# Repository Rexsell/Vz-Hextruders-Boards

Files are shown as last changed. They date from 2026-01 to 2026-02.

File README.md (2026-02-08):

This project introduces convenient and useful PCBs designed for the [Vz-Hextrudort-Low](https://github.com/VzBoT3D/Vz-HextrudORT) and [Vz-Hextrudort-Plus](https://aliexpress.com/item/1005006121253410.html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)
Currently, there are no fully suitable toolboards for VzHextruders, as existing options require additional printed parts and are not 100% compatible with the [Vz-Printhead](https://github.com/VzBoT3D/Vz-Printhead-CNC)

# Prerequisites

Before installation, ensure you have a compatible [X-Endstop mount](https://www.printables.com/model/1297201-x-endstop-mount)
Also, use the correct hardware:
- M3x25 screw (for both extruders)
- M3x6 screw (Hextrudort-Low)
- M3x16 screw (Hextrudort-Plus)
- M3 standoffs (Length equal to your motor's height. You may also need a 0.5mm spacer for LDO motors.)
  
# Boards

## [VzHextrudortLow](https://github.com/Rexsell/Vz-Hextrudort-Boards/tree/main/VzHextrudortLow "VzHextrudortLow") and [VzHextrudortPlus](https://github.com/Rexsell/Vz-Hextrudort-Boards/tree/main/VzHextrudortPlus "VzHextrudortPlus")

They are simple commutation boards, they require Molex Microfit 2x10 as an input. Just direct connection, simple yet useful.

<p align="left">
  Vz-Hextrudort-Low
  Vz-Hextrudort-Plus
</p>

## [VzHextrudortPlusCan](https://github.com/Rexsell/Vz-Hextrudort-Boards/tree/main/VzHextrudortPlusCan "VzHextrudortPlusCan") and [VzHextrudortPlusUSB](https://github.com/Rexsell/Vz-Hextrudort-Boards/tree/main/VzHextrudortPlusUSB "VzHextrudortPlusUSB")
These are already CAN and USB boards respectively. USB version has several additional USB connectors for Beacon/Cartographer sensors and other devices. CAN board has only one CAN connector for external devices.

First of all, they are simpled version of toolboards. They were made as two-layer, singlesided PCBs in order to reduce cost and make them assemblable at home.
Secondly, CAN version I ordered and assembled two times, second one I corrected several mistakes. 

Features:
- Onboard NTC sensor
- TMC2209
- Connectors for external probes
- Connector for FilGuard sensor (Supports simple endstop)
- MAX31865 (Only for USB version curently)
- Solder jumper to turn off power LEDs
- RGB LED for motor backlight (Only for USB)
- Molex Microfit 3.0 for heater
- PFET protection from reversed polarity
- 2 Fans connectors
  
<p align="left">
  Hextruder Photo
  Hextruder Photo 2
</p>

## WARNING!!!

**Before using this project, double-check the hotnd sensor connector schematic. I experienced unstable readings due to this configuration. The cause could be poorly chosen components, suboptimal routing, or a faulty schematic. The issue was completely resolved after connecting the same PT1000 sensor to a MAX31865 board. I used the BTT EBB36 schematic as a reference, but I don't recall exactly how I selected the components — I may have chosen incorrect ones.**

## [VzLowCan-Pro](https://github.com/Rexsell/Vz-Hextrudort-Boards/tree/main/VzLowCan-Pro "VzLowCan-Pro")

It shares the same features (and issues) as the [VzHextrudortPlusUSB](https://github.com/Rexsell/Vz-Hextrudort-Boards/tree/main/VzHextrudortPlusUSB "VzHextrudortPlusUSB"). However, this version is adapted for the -Low model and includes several additional features, such as an extended configuration for the MAX31865 and a connector for a probe like the BL-Touch. It also has a jumper for fan voltage selection. The design is not yet finalized, but I believe more experienced engineers will be able to complete it.

<p align="left">
  VzLowCan-Pro
  VzLowCan-Pro SolidWorks
</p>

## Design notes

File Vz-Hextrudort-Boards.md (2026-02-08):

This project introduces convenient and useful PCBs designed for the [Vz-Hextrudort-Low](https://github.com/VzBoT3D/Vz-HextrudORT) and [Vz-Hextrudort-Plus](https://aliexpress.com/item/1005006121253410.html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)
Currently, there are no fully suitable toolboards for VzHextruders, as existing options require additional printed parts and are not 100% compatible with the [Vz-Printhead](https://github.com/VzBoT3D/Vz-Printhead-CNC)

# Prerequisites

Before installment, make sure you have suitable [X-Endstop mount](https://www.printables.com/model/1297201-x-endstop-mount)
Also, use proper hardware:
- M3x25 screw (for both extruders)
- M3x6 screw (Hextrudort-Low)
- M3x16 screw (Hextrudort-Plus)
- M3 standoffs (Equals for your motor length. You may also need 0.5 spacer for LDO motors)
# Boards

## [VzHextrudortLow](https://github.com/Rexsell/Vz-Hextrudort-Boards/tree/main/VzHextrudortLow "VzHextrudortLow") and [VzHextrudortPlus](https://github.com/Rexsell/Vz-Hextrudort-Boards/tree/main/VzHextrudortPlus "VzHextrudortPlus")

They are simple commutation boards, they require Molex Microfit 2x10 as an input. Just direct connection, simple yet useful.
![[Hextrudort-Low commutation board.png]]
![[Hextrudort-Plus commutation board.png]]
## [VzHextrudortPlusCan](https://github.com/Rexsell/Vz-Hextrudort-Boards/tree/main/VzHextrudortPlusCan "VzHextrudortPlusCan") and [VzHextrudortPlusUSB](https://github.com/Rexsell/Vz-Hextrudort-Boards/tree/main/VzHextrudortPlusUSB "VzHextrudortPlusUSB")
These are already CAN and USB boards respectively. USB version has several additional USB connectors for Beacon/Cartographer sensors and other devices. CAN board has only one CAN connector for external devices.

First of all, they are simpled version of toolboards. They were made as two-layer, singlesided PCBs in order to reduce cost and make them assemblable at home.
Secondly, CAN version I ordered and assembled two times, second one I corrected several mistakes. 
![[Hextruder Photo.png]]

Features:
- Onboard NTC sensor
- TMC2209
- Connectors for external probes
- Connector for FilGuard sensor (Supports simple endstop)
- MAX31865 (Only for USB version curently)
- Solder jumper to turn off power LEDs
- RGB LED for motor backlight (Only for USB)
- Molex Microfit 3.0 for heater
- PFET protection from reversed polarity
- 2 Fans connectors

## WARNING!!!

**Before using this project, double-check the hotnd sensor connector schematic. I experienced unstable readings due to this configuration. The cause could be poorly chosen components, suboptimal routing, or a faulty schematic. The issue was completely resolved after connecting the same PT1000 sensor to a MAX31865 board. I used the BTT EBB36 schematic as a reference, but I don't recall exactly how I selected the components — I may have chosen incorrect ones.**

## [VzLowCan-Pro](https://github.com/Rexsell/Vz-Hextrudort-Boards/tree/main/VzLowCan-Pro "VzLowCan-Pro")

It shares the same features (and issues) as the [VzHextrudortPlusUSB](https://github.com/Rexsell/Vz-Hextrudort-Boards/tree/main/VzHextrudortPlusUSB "VzHextrudortPlusUSB"). However, this version is adapted for the -Low model and includes several additional features, such as an extended configuration for the MAX31865 and a connector for a probe like the BL-Touch. It also has a jumper for fan voltage selection. The design is not yet finalized, but I believe more experienced engineers will be able to complete it.
![[VzLowCan-Pro.png]]

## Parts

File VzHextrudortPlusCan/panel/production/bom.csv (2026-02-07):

Designator | Footprint | Quantity | Value | LCSC Part #
C1 | 0402 | 1 | 4.7u
C10, C11, C17, C28, C3, C33, C36, C4, C5, C7, C8, C9 | 0402 | 12 | 100n
C12 | CP_EIA-2012-12_Kemet-R | 1 | 2.2u
C13, C14 | 0603 | 2 | 4.7u
C15, C18 | 0603 | 2 | 0.1u
C16 | 0603 | 1 | 10u
C19, C20 | CP_EIA-3216-18_Kemet-A | 2 | 22u
C2, C29, C30, C31, C32, C34, C35 | 0402 | 7 | 22n
C21 | 0402 | 1 | 75p
C6 | CP_Elec_6.3x5.2 | 1 | 100u
D1 | D_SOD-123F | 1 | BZT52B10
D2, D4, D8 | D_SOD-323 | 3 | 1N5819WS
D3 | SOT-23 | 1 | BAT54S
D5 | 0402 | 1 | GREEN
D6 | 0402 | 1 | BLUE
D7, D9 | 0402 | 2 | RED
J1 | JST_XH_B4B-XH-A_1x04_P2.50mm_Vertical | 1 | Conn_01x04
J10, J3 | PinHeader_1x02_P2.00mm_Vertical | 2 | Conn_01x02
J11, J5 | Molex_Micro-Fit_3.0_43045-0200_2x01_P3.00mm_Horizontal | 2 | Conn_01x02
J12, J14 | JST_PH_B2B-PH-K_1x02_P2.00mm_Vertical | 2 | Conn_01x02
J13, J8 | JST_PH_B4B-PH-K_1x04_P2.00mm_Vertical | 2 | Conn_01x04
J2 | USB_C_Receptacle_HRO_TYPE-C-31-M-12 | 1 | USB_C_Receptacle_USB2.0
J4 | XT30PW(2+2)-M.G.B | 1 | Conn_01x04
J6 | JST_PH_B3B-PH-K_1x03_P2.00mm_Vertical | 1 | Conn_01x03
J7 | JST_PH_B5B-PH-K_1x05_P2.00mm_Vertical | 1 | Conn_01x05
L1 | 0402 | 1 | 120R@100MHz
L2 | L_APV_APH0530 | 1 | 10u
Q1 | Vishay_PowerPAK_1212-8_Single | 1 | SiS443DN
Q2 | Vishay_PowerPAK_1212-8_Single | 1 | SiS862ADN
Q3, Q4 | SOT-23 | 2 | AS3400
R1, R2 | 0805 | 2 | 0R11
R10, R25, R32, R8 | 0402 | 4 | 10
R11, R24, R33, R35, R37, R39, R4, R41, R7 | 0402 | 9 | 10k
R12 | 0402 | 1 | 100k
R13 | 0402 | 1 | 13.3k
R14 | 0402 | 1 | 50
R19 | 0402 | 1 | 1M
R20, R21 | 0402 | 2 | 5.1k
R22, R23 | 0402 | 2 | 22
R26, R31, R9 | 0402 | 3 | 20k
R27 | 0402 | 1 | 4.12k
R28, R46 | 0402 | 2 | 4.7k
R29, R30 | 0402 | 2 | 2.37k
R34, R36, R38, R40, R43 | 0402 | 5 | 1k
R42 | 0402 | 1 | 620
R44 | 0402 | 1 | 11k
R45 | 0402 | 1 | 1.5k
R5, R6 | 0402 | 2 | 60
SW1, SW2 | SW_Push_1P1T_NO_Vertical_Wuerth_434133025816 | 2 | SW_Push
TH1 | 0402 | 1 | KNTC0402/100KF3950
U1 | LQFP-48_7x7mm_P0.5mm | 1 | STM32G0B1CBTx
U2 | VQFN-28-1EP_5x5mm_P0.5mm_EP3.7x3.7mm | 1 | TMC2209-LA
U3 | SOIC-8_3.9x4.9mm_P1.27mm | 1 | SN65HVD1050D
U4 | SOT-23-5 | 1 | 74LVC1G17D
U5 | SOT-23-5 | 1 | ME6211C33M5
U6 | SOT-23-6 | 1 | TPS54302
Y1 | Crystal_SMD_3225-4Pin_3.2x2.5mm | 1 | 8MhZ

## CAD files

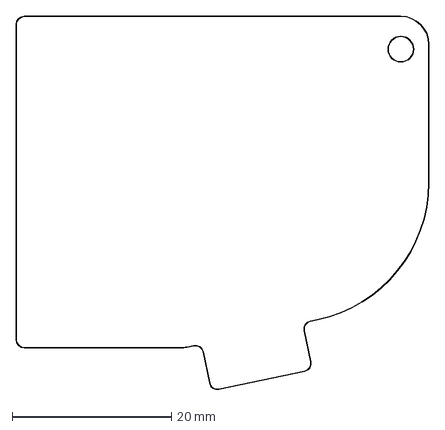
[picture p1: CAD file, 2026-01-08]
VzHextrudortLow/VzHexPCB.DXF
51.8 x 46.9 mm

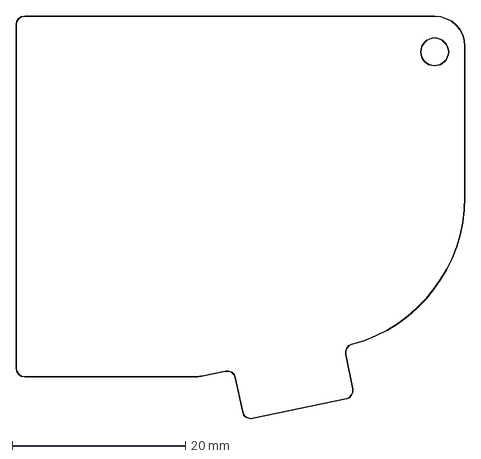
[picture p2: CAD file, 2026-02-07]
VzHextrudortPlusCan/PCB_Mockup.DXF
51.8 x 46.5 mm

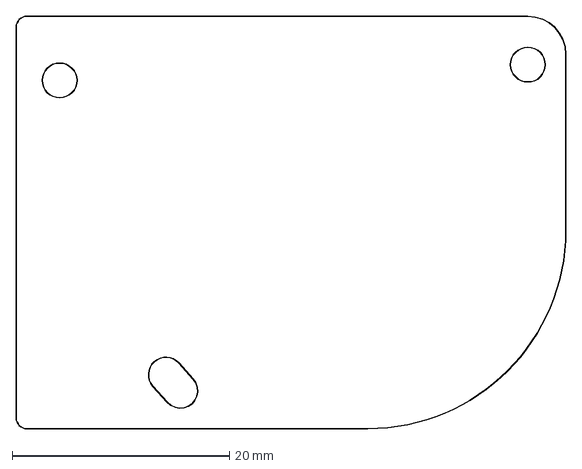
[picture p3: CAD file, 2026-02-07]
VzLowCan-Pro/VzHexLowPCB.DXF
50.6 x 38.0 mm

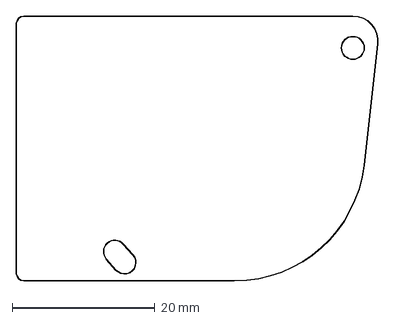
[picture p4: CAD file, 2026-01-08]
VzHextrudortLow/VzHexLowPCB.DXF
50.7 x 37.0 mm

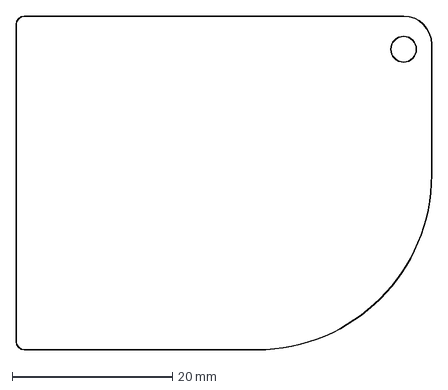
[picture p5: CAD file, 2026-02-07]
VzLowCan-Pro/VzHexPCB.DXF
51.8 x 41.6 mm

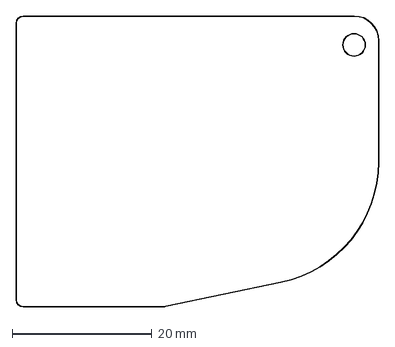
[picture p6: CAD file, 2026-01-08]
VzLowCan-Pro/VzHexPCB2.DXF
51.8 x 41.6 mm

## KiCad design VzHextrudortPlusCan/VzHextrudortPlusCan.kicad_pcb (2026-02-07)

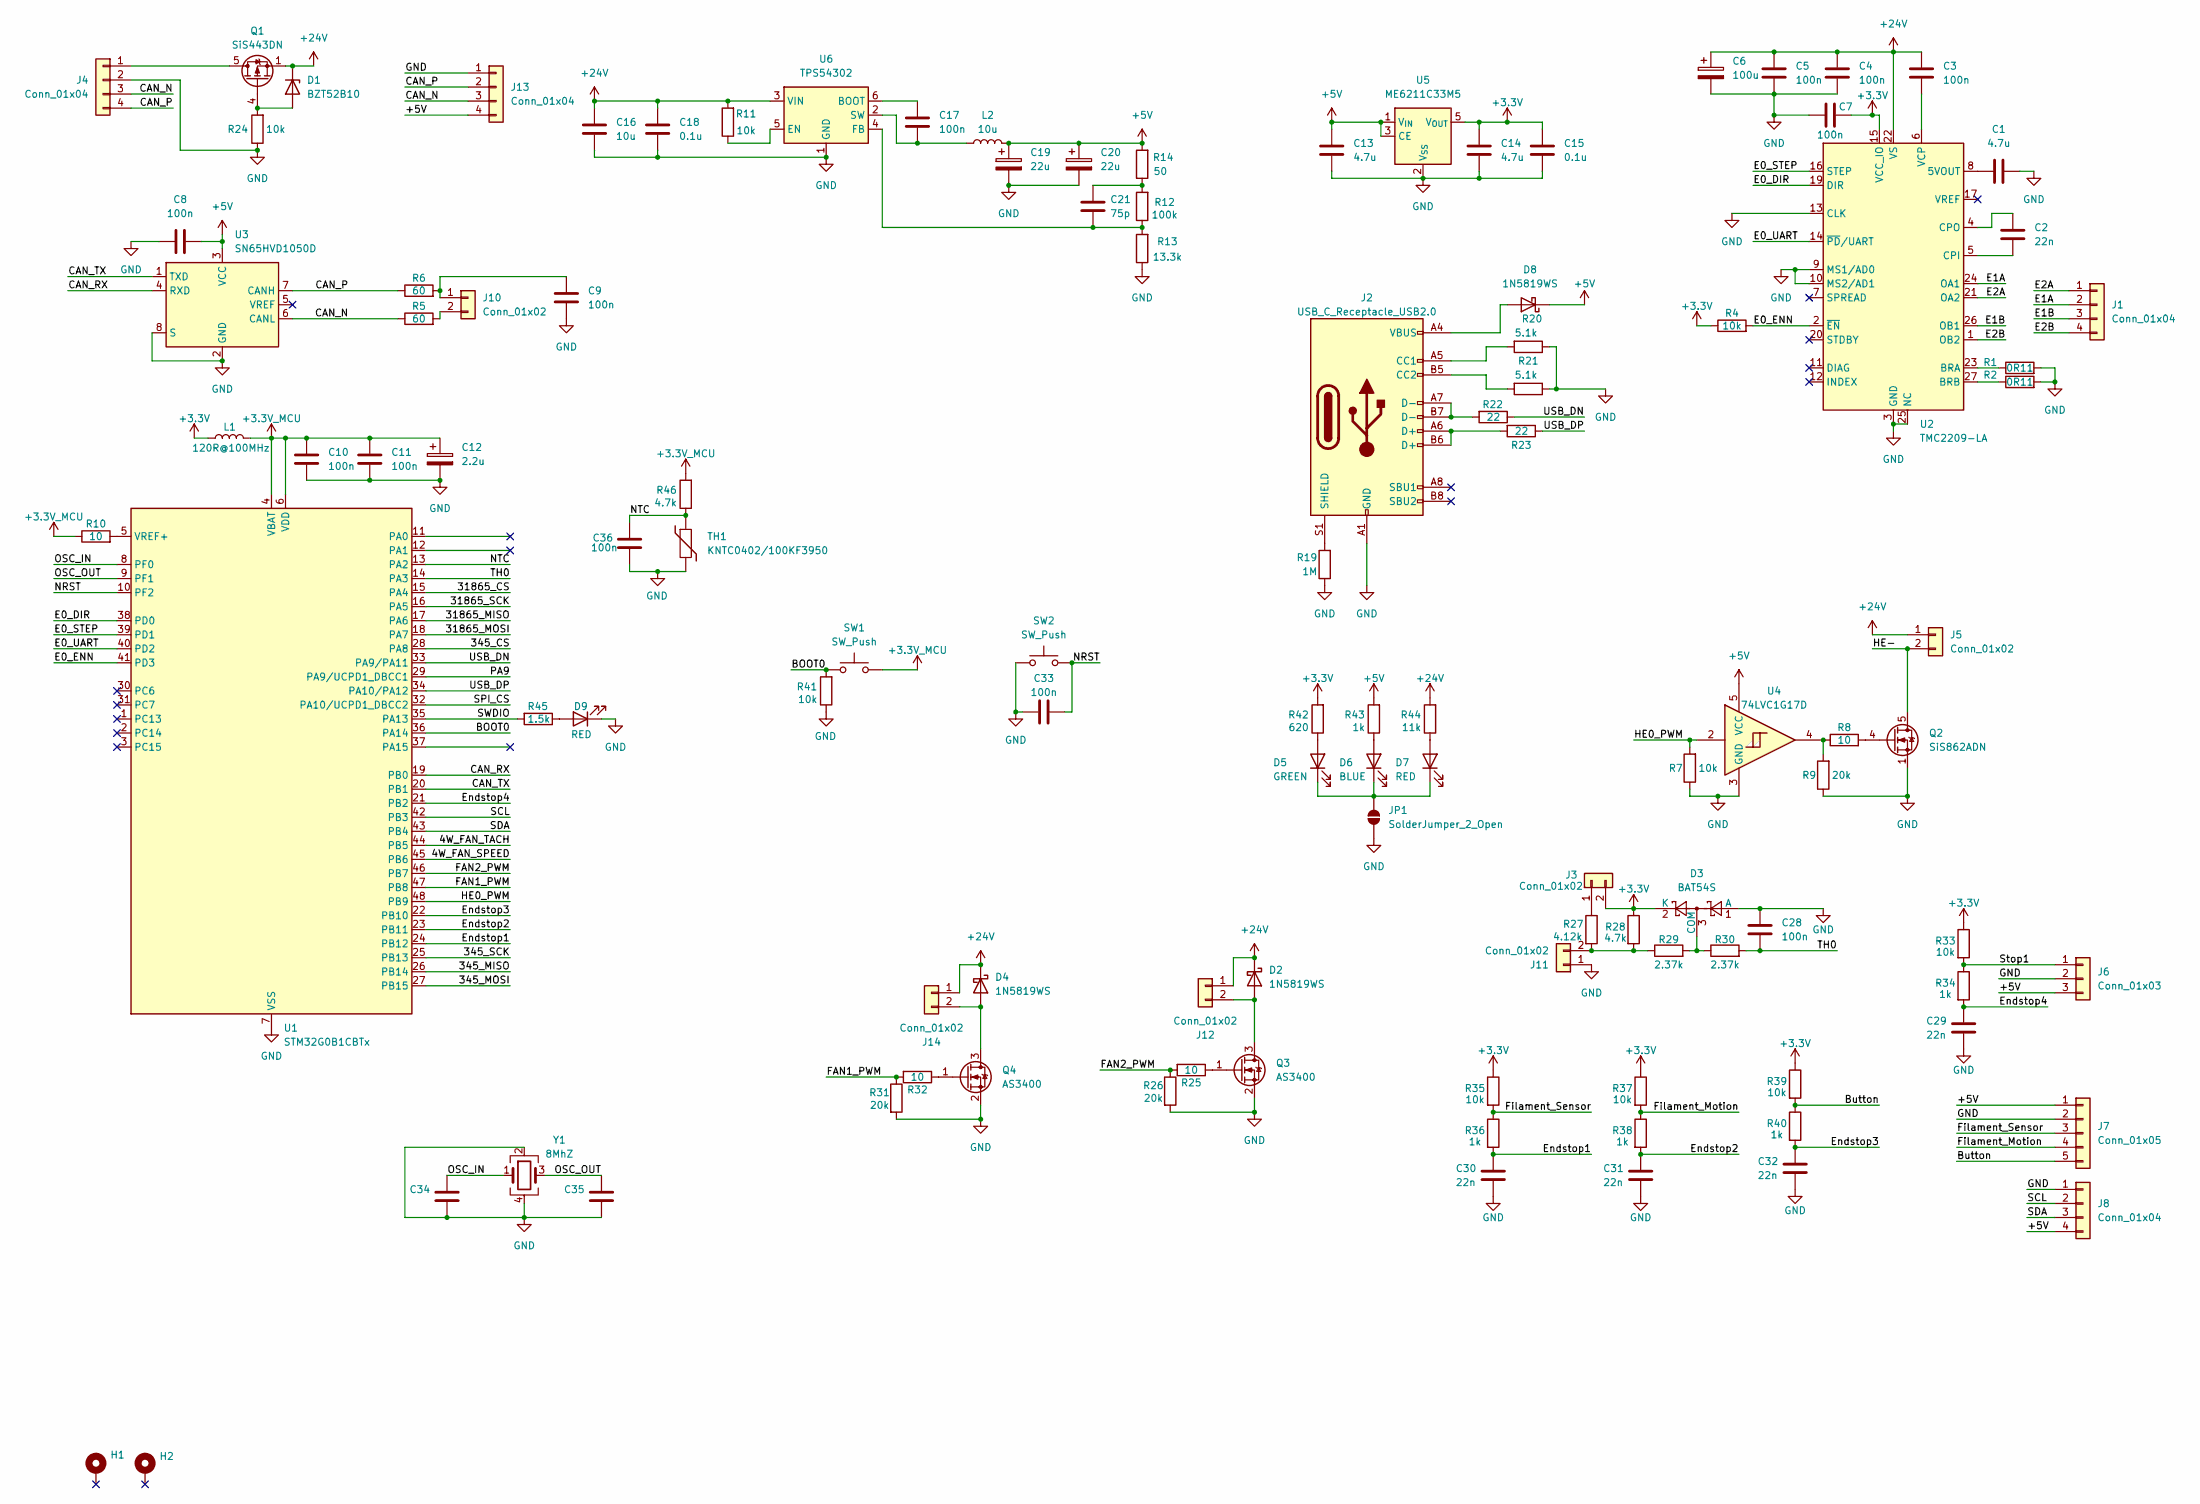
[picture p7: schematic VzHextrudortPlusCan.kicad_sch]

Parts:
C1: 4.7u; C_0402_1005Metric
C2, C29, C30, C31, C32, C34, C35: 22n; C_0402_1005Metric
C3, C4, C5, C7, C8, C9, C10, C11, C17, C28, C33, C36: 100n; C_0402_1005Metric
C6: 100u; CP_Elec_6.3x5.2
C12: 2.2u; CP_EIA-2012-12_Kemet-R
C13, C14: 4.7u; C_0603_1608Metric
C15, C18: 0.1u; C_0603_1608Metric
C16: 10u; C_0603_1608Metric
C19, C20: 22u; CP_EIA-3216-18_Kemet-A
C21: 75p; C_0402_1005Metric
D1: BZT52B10; D_SOD-123F
D2, D4, D8: 1N5819WS; D_SOD-323
D3: BAT54S; SOT-23
D5: GREEN; LED_0402_1005Metric
D6: BLUE; LED_0402_1005Metric
D7, D9: RED; LED_0402_1005Metric
H1, H2: MountingHole_Pad; MountingHole_M3
J1: Conn_01x04; JST_XH_B4B-XH-A_1x04_P2.50mm_Vertical
J2: USB_C_Receptacle_USB2.0; USB_C_Receptacle_HRO_TYPE-C-31-M-12
J3, J10: Conn_01x02; PinHeader_1x02_P2.00mm_Vertical
J4: Conn_01x04; XT30PW(2+2)-M.G.B
J5, J11: Conn_01x02; Molex_Micro-Fit_3.0_43045-0200_2x01_P3.00mm_Horizontal
J6: Conn_01x03; JST_PH_B3B-PH-K_1x03_P2.00mm_Vertical
J7: Conn_01x05; JST_PH_B5B-PH-K_1x05_P2.00mm_Vertical
J8, J13: Conn_01x04; JST_PH_B4B-PH-K_1x04_P2.00mm_Vertical
J12, J14: Conn_01x02; JST_PH_B2B-PH-K_1x02_P2.00mm_Vertical
JP1: SolderJumper_2_Open; SolderJumper-2_P1.3mm_Open_TrianglePad1.0x1.5mm
L1: 120R@100MHz; L_0402_1005Metric
L2: 10u; L_APV_APH0530
Q1: SiS443DN; Vishay_PowerPAK_1212-8_Single
Q2: SiS862ADN; Vishay_PowerPAK_1212-8_Single
Q3, Q4: AS3400; SOT-23
R1, R2: 0R11; R_0805_2012Metric
R4, R7, R11, R24, R33, R35, R37, R39: 10k; R_0402_1005Metric
R5, R6: 60; R_0402_1005Metric
R8, R10, R25, R32: 10; R_0402_1005Metric
R9, R26, R31: 20k; R_0402_1005Metric
R12: 100k; R_0402_1005Metric
R13: 13.3k; R_0402_1005Metric
R14: 50; R_0402_1005Metric
R19: 1M; R_0402_1005Metric
R20, R21: 5.1k; R_0402_1005Metric
R22, R23: 22; R_0402_1005Metric
R27: 4.12k; R_0402_1005Metric
R28: 4.7k; R_0402_1005Metric
R29, R30: 2.37k; R_0402_1005Metric
R34, R36, R38, R40: 1k; R_0402_1005Metric
R41: 10k; R_0402_1005Metric; Part Description Resistor 15K M1005 1% 63mW
R42: 620; R_0402_1005Metric; Part Description Resistor 15K M1005 1% 63mW
R43: 1k; R_0402_1005Metric; Part Description Resistor 15K M1005 1% 63mW
R44: 11k; R_0402_1005Metric; Part Description Resistor 15K M1005 1% 63mW
R45: 1.5k; R_0402_1005Metric; Part Description Resistor 15K M1005 1% 63mW
R46: 4.7k; R_0402_1005Metric; Part Description Resistor 15K M1005 1% 63mW
SW1, SW2: SW_Push; SW_Push_1P1T_NO_Vertical_Wuerth_434133025816
TH1: KNTC0402/100KF3950; R_0402_1005Metric
U1: STM32G0B1CBTx; LQFP-48_7x7mm_P0.5mm
U2: TMC2209-LA; VQFN-28-1EP_5x5mm_P0.5mm_EP3.7x3.7mm
U3: SN65HVD1050D; SOIC-8_3.9x4.9mm_P1.27mm
U4: 74LVC1G17D; SOT-23-5
U5: ME6211C33M5; SOT-23-5
U6: TPS54302; SOT-23-6
Y1: 8MhZ; Crystal_SMD_3225-4Pin_3.2x2.5mm

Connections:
+3.3V: C7.1, C14.1, C15.1, D3.2 (K), J3.2, L1.1, R4.1, R28.1, R33.1, R35.1, R37.1, R39.1, R42.2, U2.15 (VCC_IO), U5.5 (V_{OUT})
+3.3V_MCU: C10.2, C11.2, C12.1, L1.2, R10.1, R46.2, SW1.2, U1.4 (VBAT), U1.6 (VDD)
+5V: C8.1, C13.1, C19.1, C20.1, D8.1 (K), J6.3, J7.1, J8.4, J13.4, L2.2, R14.2, R43.2, U3.3 (VCC), U4.5 (VCC), U5.1 (V_{IN}), U5.3 (CE)
+24V: C3.2, C4.2, C5.2, C6.1, C16.1, C18.1, D1.1 (K), D2.1 (K), D4.1 (K), J5.1, J12.1, J14.1, Q1.1 (S), Q1.2 (S), Q1.3 (S), R11.2, R44.2, U2.22 (VS), U2.28 (VS), U6.3 (VIN)
/4W_FAN_SPEED: U1.45 (PB6)
/4W_FAN_TACH: U1.44 (PB5)
/345_CS: U1.28 (PA8)
/345_MISO: U1.26 (PB14)
/345_MOSI: U1.27 (PB15)
/345_SCK: U1.25 (PB13)
/31865_CS: U1.15 (PA4)
/31865_MISO: U1.17 (PA6)
/31865_MOSI: U1.18 (PA7)
/31865_SCK: U1.16 (PA5)
/BOOT0: R41.2, SW1.1, U1.36 (PA14)
/Button: J7.5, R39.2, R40.1
/CAN_N: J4.3, J13.3, R5.1, U3.6 (CANL)
/CAN_P: J4.4, J13.2, R6.1, U3.7 (CANH)
/CAN_RX: U1.19 (PB0), U3.4 (RXD)
/CAN_TX: U1.20 (PB1), U3.1 (TXD)
/E0_DIR: U1.38 (PD0), U2.19 (DIR)
/E0_ENN: R4.2, U1.41 (PD3), U2.2 (~EN)
/E0_STEP: U1.39 (PD1), U2.16 (STEP)
/E0_UART: U1.40 (PD2), U2.14 (~PD/UART)
/E1A: J1.2, U2.24 (OA1)
/E1B: J1.3, U2.26 (OB1)
/E2A: J1.1, U2.21 (OA2)
/E2B: J1.4, U2.1 (OB2)
/Endstop1: C30.1, R36.2, U1.24 (PB12)
/Endstop2: C31.1, R38.2, U1.23 (PB11)
/Endstop3: C32.1, R40.2, U1.22 (PB10)
/Endstop4: C29.1, R34.2, U1.21 (PB2)
/FAN1_PWM: R31.1, R32.2, U1.47 (PB8)
/FAN2_PWM: R25.2, R26.1, U1.46 (PB7)
/Filament_Motion: J7.4, R37.2, R38.1
/Filament_Sensor: J7.3, R35.2, R36.1
/HE0_PWM: R7.2, U1.48 (PB9), U4.2
/HE-: J5.2, Q2.5 (D)
/NRST: C33.1, SW2.2, U1.10 (PF2)
/NTC: C36.1, R46.1, TH1.1, U1.13 (PA2)
/OSC_IN: C34.1, U1.8 (PF0), Y1.1
/OSC_OUT: C35.1, U1.9 (PF1), Y1.3
/PA9: U1.29 (PA9/UCPD1_DBCC1)
/SCL: J8.2, U1.42 (PB3)
/SDA: J8.3, U1.43 (PB4)
/SPI_CS: U1.32 (PA10/UCPD1_DBCC2)
/SWDIO: R45.2, U1.35 (PA13)
/Stop1: J6.1, R33.2, R34.1
/TH0: C28.1, R30.2, U1.14 (PA3)
/USB_DN: R22.1, U1.33 (PA9/PA11)
/USB_DP: R23.1, U1.34 (PA10/PA12)
GND: C1.2, C4.1, C5.1, C6.2, C7.2, C8.2, C9.1, C10.1, C11.1, C12.2, C13.2, C14.2, C15.2, C16.2, C18.2, C19.2, C20.2, C28.2, C29.2, C30.2, C31.2, C32.2, C33.2, C34.2, C35.2, C36.2, D3.1 (A), D9.1 (K), J2.A1 (GND), J2.A12 (GND), J2.B1 (GND), J2.B12 (GND), J4.2, J6.2, J7.2, J8.1, J11.1, J13.1, JP1.1 (A), Q2.1 (S), Q2.2 (S), Q2.3 (S), Q3.2 (S), Q4.2 (S), R1.2, R2.2, R7.1, R9.1, R13.1, R19.1, R20.1, R21.1, R24.1, R26.2, R31.2, R41.1, SW2.1, TH1.2, U1.7 (VSS), U2.3 (GND), U2.9 (MS1/AD0), U2.10 (MS2/AD1), U2.13 (CLK), U2.18 (GND), U2.25 (NC), U2.29 (GND), U3.2 (GND), U3.8 (S), U4.3 (GND), U5.2 (V_{SS}), U6.1 (GND), Y1.2, Y1.4
unnamed: C21.2, R12.2, R14.1
unnamed: D1.2 (A), Q1.4 (G), R24.2
unnamed: D2.2 (A), J12.2, Q3.3 (D)
unnamed: D3.3 (COM), R29.2, R30.1
unnamed: D4.2 (A), J14.2, Q4.3 (D)
unnamed: D5.2 (A), R42.1
unnamed: D5.1 (K), D6.1 (K), D7.1 (K), JP1.2 (B)
unnamed: D6.2 (A), R43.1
unnamed: D7.2 (A), R44.1
unnamed: D8.2 (A), J2.A4 (VBUS), J2.A9 (VBUS), J2.B4 (VBUS), J2.B9 (VBUS)
unnamed: D9.2 (A), R45.1
unnamed: J2.A5 (CC1), R20.2
unnamed: J2.B5 (CC2), R21.2
unnamed: J2.A6 (D+), J2.B6 (D+), R23.2
unnamed: J2.A7 (D-), J2.B7 (D-), R22.2
unnamed: J2.S1 (SHIELD), R19.2
unnamed: J3.1, R27.1
unnamed: J4.1, Q1.5 (D)
unnamed: C9.2, J10.1, R6.2
unnamed: J10.2, R5.2
unnamed: J11.2, R27.2, R28.2, R29.1
unnamed: Q2.4 (G), R8.2
unnamed: Q3.1 (G), R25.1
unnamed: Q4.1 (G), R32.1
unnamed: R8.1, R9.2, U4.4
unnamed: R10.2, U1.5 (VREF+)
unnamed: C1.1, U2.8 (5VOUT)
unnamed: R1.1, U2.23 (BRA)
unnamed: R2.1, U2.27 (BRB)
unnamed: C2.1, U2.5 (CPI)
unnamed: C2.2, U2.4 (CPO)
unnamed: C3.1, U2.6 (VCP)
unnamed: C17.2, U6.6 (BOOT)
unnamed: R11.1, U6.5 (EN)
unnamed: C21.1, R12.1, R13.2, U6.4 (FB)
unnamed: C17.1, L2.1, U6.2 (SW)

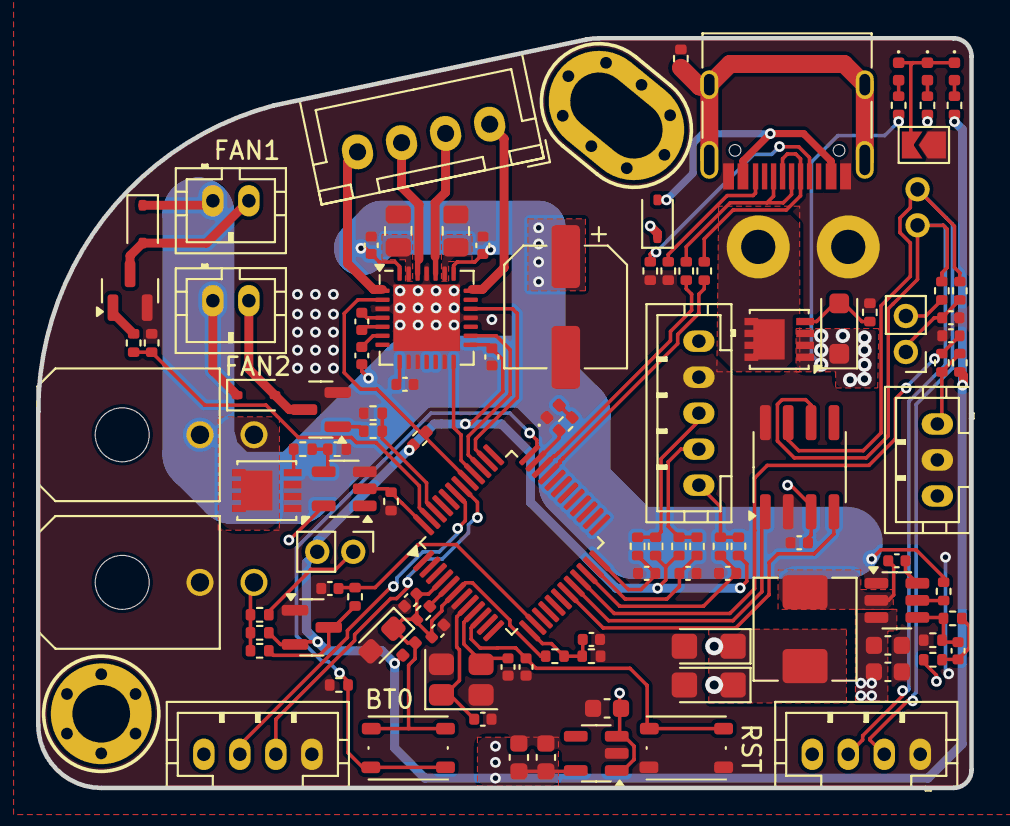
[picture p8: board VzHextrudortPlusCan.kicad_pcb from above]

Board: 2 copper layers, 51.8 x 41.6 mm, 112 parts (1 on the bottom side), 76 nets.

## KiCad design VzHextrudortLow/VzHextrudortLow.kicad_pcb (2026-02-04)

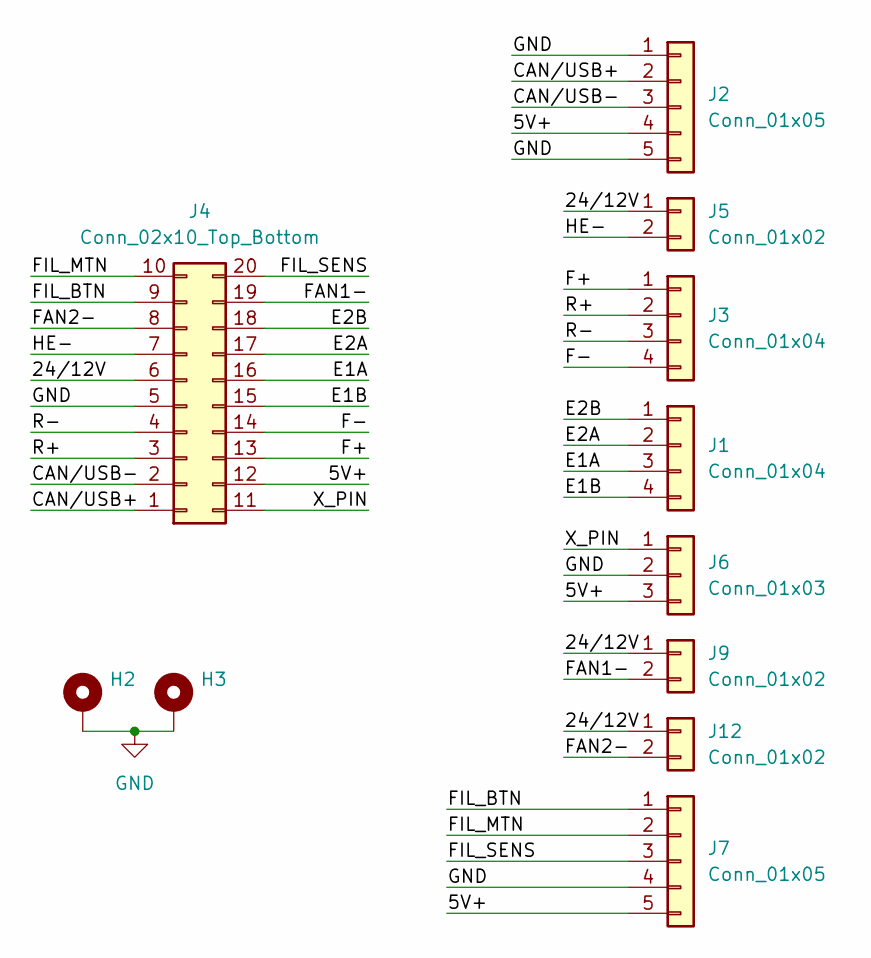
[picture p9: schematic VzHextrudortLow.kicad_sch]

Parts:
H2, H3: MountingHole_Pad; MountingHole_M3
J1: Conn_01x04; JST_XH_S4B-XH-A_1x04_P2.50mm_Horizontal
J2, J7: Conn_01x05; JST_PH_B5B-PH-K_1x05_P2.00mm_Vertical
J3: Conn_01x04; JST_PH_B4B-PH-K_1x04_P2.00mm_Vertical
J4: Conn_02x10_Top_Bottom; Molex_Micro-Fit_3.0_43045-2012_2x10_P3.00mm_Vertical
J5: Conn_01x02; Molex_Micro-Fit_3.0_43045-0200_2x01_P3.00mm_Horizontal
J6: Conn_01x03; JST_PH_B3B-PH-K_1x03_P2.00mm_Vertical
J9, J12: Conn_01x02; JST_PH_B2B-PH-K_1x02_P2.00mm_Vertical

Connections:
/5V+: J2.4, J4.12, J6.3, J7.5
/24/12V: J4.6, J5.1, J9.1, J12.1
/CAN/USB+: J2.2, J4.1
/CAN/USB-: J2.3, J4.2
/E1A: J1.3, J4.16
/E1B: J1.4, J4.15
/E2A: J1.2, J4.17
/E2B: J1.1, J4.18
/F+: J3.1, J4.13
/F-: J3.4, J4.14
/FAN1-: J4.19, J9.2
/FAN2-: J4.8, J12.2
/FIL_BTN: J4.9, J7.1
/FIL_MTN: J4.10, J7.2
/FIL_SENS: J4.20, J7.3
/HE-: J4.7, J5.2
/R+: J3.2, J4.3
/R-: J3.3, J4.4
/X_PIN: J4.11, J6.1
GND: H2.1, H3.1, J2.1, J2.5, J4.5, J6.2, J7.4

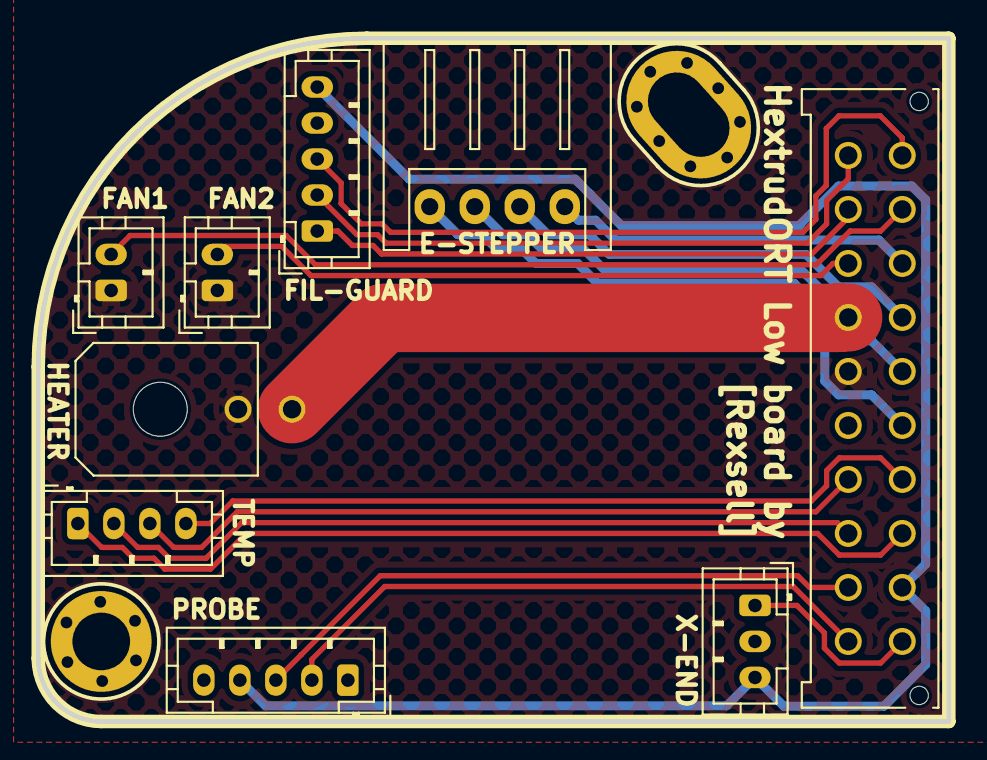
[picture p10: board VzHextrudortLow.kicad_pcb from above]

Board: 2 copper layers, 50.6 x 38.0 mm, 11 parts (0 on the bottom side), 20 nets.

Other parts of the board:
H1: MountingHole_Pad; MountingHole_M3
